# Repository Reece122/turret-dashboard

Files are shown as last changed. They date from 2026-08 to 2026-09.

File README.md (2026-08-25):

<div align="center">

# AutoTurret

**A camera-driven, object-tracking pan/tilt turret** — Jetson-hosted vision, a
closed-loop control law tuned in simulation before it ever touched hardware,
and a live web dashboard to run and tune it from any device on the network.







</div>

<br>

<p align="center">
  <video src="media/drone-3rd-person.mov" controls width="100%">
    Demo video — see <code>media/drone-3rd-person.mov</code>.
  </video>
</p>

---

## Demo

**Drone tracking**

| 3rd person | Dashboard POV |
|---|---|
| <video src="media/drone-3rd-person.mov" controls width="100%"></video> | <video src="media/drone-dashboard-pov.mov" controls width="100%"></video> |

**Ball tracking** — same control law, three motion patterns

| Straight-line | Figure-8 | Pinpoint (acquire/reacquire) |
|---|---|---|
| <video src="media/ball-line.mov" controls width="100%"></video> | <video src="media/ball-figure8.mov" controls width="100%"></video> | <video src="media/ball-pinpoint.mov" controls width="100%"></video> |

## What it is

Two processes talking over HTTP: a **Python/Flask vision server** that owns
the camera, runs YOLO11 detection, and drives two servos over I2C; and a
**Next.js dashboard** that streams the annotated feed, exposes every control
gain as a live slider, and can start/stop/restart the vision server remotely.
Point it at a moving target and it tracks and aims a laser at it in real time.

The interesting part isn't the demo — it's getting from "twitches on a
stationary target, lags behind a fast one" to a single, stable control law
that handles both. That's documented in full in **[DEVLOG.md](DEVLOG.md)**.

## Highlights

- **Velocity feedforward control** — commands the target's own angular rate
  directly instead of waiting for position error to build up, collapsing what
  used to be a fragile two-mode (acquire/track) state machine into one gain
  that's stable at every speed. [Details →](DEVLOG.md#2-the-tracking-control-saga-the-big-one)
- **World-space tracking** — target velocity is estimated in world space
  (image position + camera angle), not image space, so panning to follow the
  target is never mistaken for the target moving.
- **Custom-trained YOLO11 detector** — a from-scratch drone detector
  (mAP@50 0.976) trained and fine-tuned on the Jetson itself, alongside a
  from-scratch OpenCV blob tracker as a no-neural-net fallback mode.
- **Simulated before it was tuned on hardware** — every control-law and gain
  change was validated in a closed-loop 2D simulator first; hardware time was
  spent confirming, not guessing. See `tools/tune.py`.
- **Face-safety clamp** — with an always-on laser payload, aim is hard-clamped
  to at or below the shoulder line whenever the target class is a person.
- **Fully live-tunable** — every PID/Kalman/feedforward gain, camera setting,
  and servo limit is a dashboard slider with immediate effect — no redeploy
  to tune.

## How it works

| Piece | Detail |
|---|---|
| Compute | Jetson Orin Nano 8GB, JetPack 6.2.3 |
| Vision | YOLO11 (pose + custom drone detector) and an OpenCV blob tracker |
| Control | PID + velocity feedforward on a Kalman-filtered world-space estimate |
| Actuation | 2x servos via PCA9685 over I2C |
| Payload | Always-on laser designator |
| Backend | `python_server.py` — Flask + MJPEG stream + vision/control thread, port 8000 |
| Frontend | Next.js 16 / React 19 dashboard, `app/page.tsx`, port 3000 |
| Test rig | `tools/drone_target.html` — animated on-screen target for indoor tuning |

```
┌────────────────────┐        spawns/kills, proxies stream        ┌───────────────────────┐
│  Next.js dashboard  │ ───────────────────────────────────────▶  │  Flask vision server   │
│  (port 3000)        │ ◀───────────────────────────────────────  │  (port 8000)           │
│  live config sliders│        MJPEG feed + telemetry JSON         │  camera → YOLO11/blob  │
└────────────────────┘                                            │  → Kalman → PID+FF     │
                                                                    │  → PCA9685 → servos    │
                                                                    └───────────────────────┘
```

## Hardware & CAD

Full wiring, power domains, and bring-up steps are in **[HARDWARE.md](HARDWARE.md)**.

<p align="center">
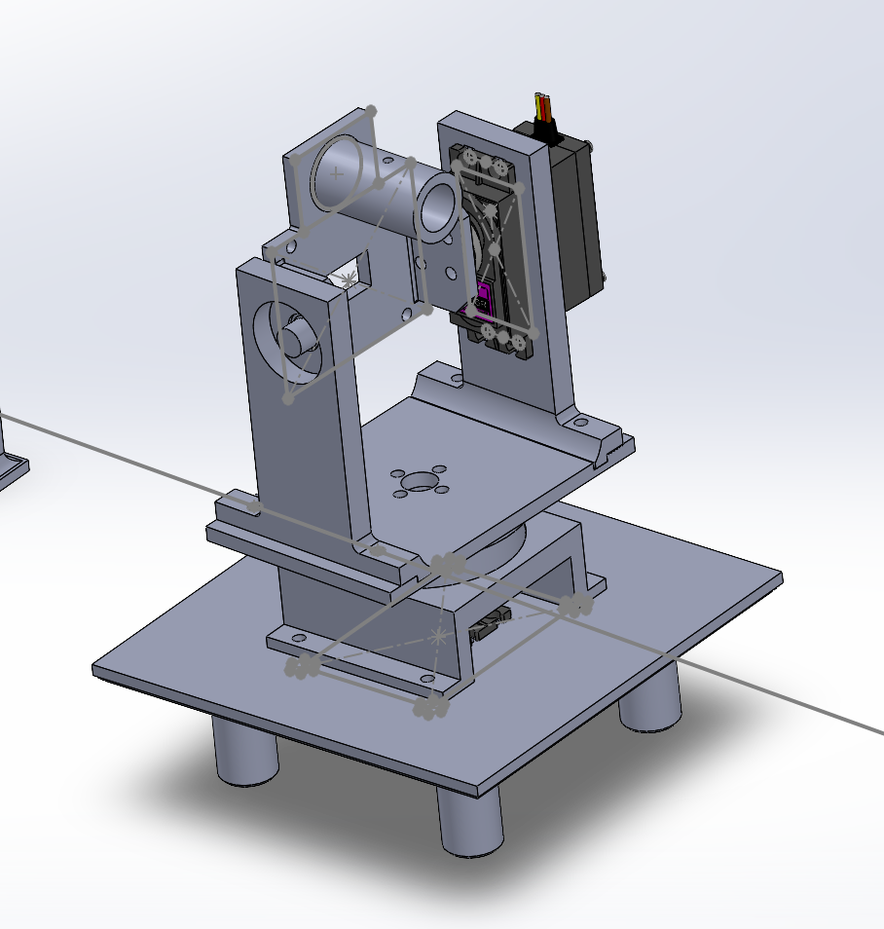
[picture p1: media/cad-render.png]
AutoTurret CAD assembly — pan/tilt mount with servo gearing
  
</p>

CAD source lives in [`/cad`](cad):

| File | Format | Notes |
|---|---|---|
| [`FinalAssembly.SLDASM`](cad/FinalAssembly.SLDASM) | SolidWorks assembly | Full turret assembly, parametric |

## Tech stack

**Frontend:** Next.js 16, React 19, TypeScript
**Backend:** Python, Flask, OpenCV, NumPy
**Vision:** Ultralytics YOLO11 (pose + custom-trained detection), custom Kalman filter
**Hardware:** NVIDIA Jetson Orin Nano, PCA9685 servo driver, 2x hobby servos, USB camera, laser module

## Getting started

```bash
# one-time Jetson setup (Node, Python deps, I2C, systemd service)
sudo bash jetson_setup.sh

# dev — dashboard only (vision server is started from the UI's Start button)
npm run dev

# or reachable from other devices on the LAN
npm run dev:lan
```

The dashboard's **Start** button spawns `python_server.py` (see
`app/api/server/route.ts`); it isn't run manually. With no PCA9685 attached,
servo output degrades to a silent no-op so the vision loop still runs
standalone (e.g. on a laptop against `tools/drone_target.html`).

## Project journal

**[DEVLOG.md](DEVLOG.md)** is the full build log — nine failed approaches to
the tracking-control bug before the actual fix, the 9→15 FPS camera-driver
investigation, the drone-detector training runs, and every hardware bump
along the way. Written to capture *why*, not just *what*, so worth a read if
you want the engineering story rather than just the code.

## Roadmap

Next up, in priority order (latency is the documented bottleneck on
everything below it — see [DEVLOG §12](DEVLOG.md#12-roadmap--planned-improvements)):

1. **Camera fps + quality** — current ~15fps ceiling is USB/MJPG-decode
   throughput; a better sensor fixes both fps and image quality at once.
2. **Better, smoother servos** — hobby-grade MG996R are the current
   mechanical noise floor.
3. **Two-camera distance triangulation** — stereo rig flanking the laser for
   a real distance estimate, not just parallax correction.
4. **Vision model quality** — more/varied training data for the drone
   detector.

## License

No license file yet — all rights reserved by default until one is added.

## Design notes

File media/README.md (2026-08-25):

# Media

Demo footage embedded in the root `README.md`:

| File | Shows |
|---|---|
| `drone-3rd-person.mov` | Tracking a drone target, 3rd-person view (also the hero clip) |
| `drone-dashboard-pov.mov` | Same drone run, from the live dashboard's feed |
| `ball-line.mov` | Ball tracking, straight-line motion |
| `ball-figure8.mov` | Ball tracking, figure-8 motion |
| `ball-pinpoint.mov` | Ball tracking, pinpoint mode (target pops up/vanishes — forces a genuine re-acquire) |
| `cad-render.png` | CAD assembly render, used in the Hardware & CAD section |

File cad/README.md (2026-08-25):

# CAD

| File | Format | Notes |
|---|---|---|
| `FinalAssembly.SLDASM` | SolidWorks assembly | Full turret assembly, parametric. Requires SolidWorks (or eDrawings) to open — no STL/step export included yet. |

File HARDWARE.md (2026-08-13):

# AutoTurret — Hardware wiring

Mental model: **three separate power domains that share one common ground.**
Never cross the rails — the only thing shared across all three is ground.

## Power domains
- **19V barrel-jack supply → Jetson only.**
- **5–6V brick (≥5A) → the PCA9685 V+ screw terminal only** (this powers the servos).
- **3.3V from the Jetson → the PCA9685 VCC** (logic only).

## Jetson 40-pin → PCA9685 (4-wire I2C link)
| Jetson pin | → | PCA9685 |
|---|---|---|
| 3.3V (pin 1) | → | VCC |
| GND (pin 6) | → | GND |
| SDA (pin 3) | → | SDA |
| SCL (pin 5) | → | SCL |

I2C is on **bus 7** on the Orin Nano. Verify the board with:
```bash
sudo i2cdetect -y -r 7      # expect 0x40 to appear
```

## Servo power → PCA9685
- 5–6V brick **+** and **−** → the green **V+ / GND** screw terminal.
- Add a **470–1000µF capacitor** across V+/GND to absorb current spikes.

## PCA9685 → servos
- **Pan servo → channel 0** (3-pin plug: signal / V+ / GND)
- **Tilt servo → channel 1**
- Servos draw power straight from the V+ rail through those headers — no separate wiring.

## Camera
- USB webcam straight into a Jetson USB port. Works with `cv2.VideoCapture(0)`.

## Laser (CHT1230, 3–6V module)
**DECISION: always-on.** No MOSFET, no GPIO, no code — the laser is lit whenever
the rig is powered.
- Wiring: red → 5V (pin 2), black → any GND pin.

<details><summary>Switchable option (not used — kept for reference)</summary>

MOSFET low-side switch:
- red → 5V
- black → MOSFET **drain**
- MOSFET **source** → GND
- Jetson **GPIO (pin 7)** → MOSFET **gate** through **~220Ω**, with a **10kΩ gate-to-source pulldown**.
</details>

## Common ground (do not skip)
Jetson GND, PCA9685 GND, and the 5–6V brick's minus **must all tie together**.
The GND wire in the 4-wire link plus the brick's minus wire already accomplish this.
Without it the servo signals float and jitter.

## Software notes
- Servo driver: `pip3 install adafruit-circuitpython-servokit`; enable I2C.
- **Servo control is implemented** in `python_server.py` (`ServoController`).
  `pan_angle` / `tilt_angle` (0–180°) are written to the PCA9685 each frame.
  With no board attached it degrades to a silent no-op ("sim" mode) so the
  vision loop still runs on a laptop.
- Laser: always-on, hardwired to 5V — no code.
- These live in `turret_config.json` (also settable via `POST /config`), so the
  mechanism can't over-travel and axes can be flipped without rewiring:
  - `servo_enabled` (master on/off), `pan_channel` (0), `tilt_channel` (1)
  - `pan_min` / `pan_max`, `tilt_min` / `tilt_max` (degrees)
  - `pan_invert` / `tilt_invert` (reverse an axis that chases the wrong way)
- First bring-up tip: set `servo_enabled` false, confirm the pan/tilt readouts
  on the dashboard move sanely, then enable. If an axis runs to its limit,
  flip that axis's `invert`.

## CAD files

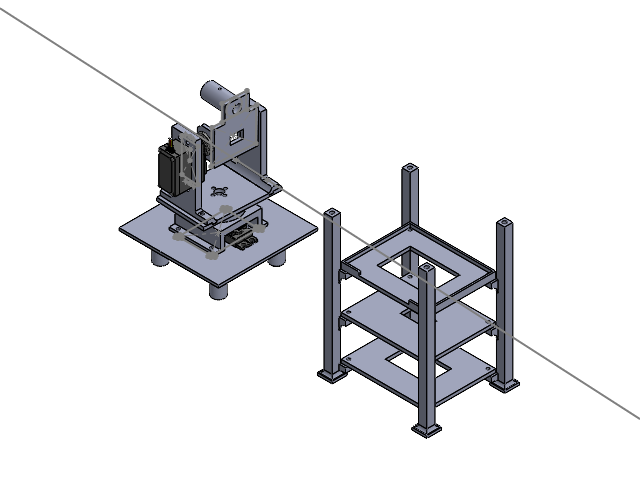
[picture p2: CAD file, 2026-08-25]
cad/FinalAssembly.SLDASM
mg996_arm_round x 2
mg996R_v2 x 2
ThrustBearing

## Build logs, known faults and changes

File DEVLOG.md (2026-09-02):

# AutoTurret — Development Log

A record of the software work on this project: what was built, what was tried,
what broke, and *why* it broke. Written to save re-deriving the same conclusions
(and re-making the same mistakes) later.

---

## 1. System overview

| Piece | Detail |
|---|---|
| Compute | Jetson Orin Nano 8GB, JetPack 6.2.3 |
| Vision | YOLO11 (pose + custom drone detector) and an OpenCV blob tracker |
| Actuation | 2x MG996R servos via PCA9685 over I2C bus 7 |
| Payload | Always-on laser (drives the face-safety logic) |
| Backend | `python_server.py` — Flask + MJPEG stream + single vision thread, port 8000 |
| Frontend | Next.js 16 / React 19 dashboard, `app/page.tsx`, port 3000 |
| Test rig | `tools/drone_target.html` — animated on-screen target |
| Access | Tailscale + LAN; SSH alias `jetson` |

Two processes, and the distinction matters constantly:

- **Dashboard (3000)** — Next.js. Serves the UI, and spawns/kills the vision server
  via `app/api/server/route.ts`.
- **Vision server (8000)** — Python. Owns the camera, inference, PID, servos.

---

## 2. The tracking-control saga (the big one)

This consumed the most time by far. Nine distinct approaches before the right one.

### The original problem

The turret needed aggressive lead + P gain to keep up with a fast target, but
those same settings made it twitch, lurch, or oscillate when the target was slow
or stationary. The intuitive fix — two modes, gentle for acquiring and aggressive
for tracking — turned out to be treating a symptom.

### Why it was actually happening (found at the end, via simulation)

The controller is `pan_angle += kp * error`, which is a **rate** command. For a
target moving at speed `v`, the steady state requires `kp * error = v * dt`, so:

```
permanent lag = v * dt / kp
```

At 15 fps with `kp = 0.09`, a 300 px/s target sits **223 px behind, forever**. The
only way to shrink that with P alone is a big `kp` — but loop delay caps `kp`
before it oscillates, and a big `kp` multiplied by a noisy velocity estimate is
precisely what makes a near-stationary target twitch.

**That bind is the entire reason the two-mode design existed.** The premise
("aggressive gains blow up on slow targets") was correct; the conclusion
("therefore switch gains") was not.

### Attempts, in order

| # | Approach | Why it failed |
|---|---|---|
| 1 | Two modes (acquire/track), switch on distance-to-crosshair | Entering track lurched the aim, which pushed the target off-center, which ejected it back to acquire. Self-reinforcing flapping. |
| 2 | Separate saved presets for acquire and track | Useful UX, but orthogonal to the bug. Didn't address why the switch misfired. |
| 3 | Gate on "consistent velocity direction for N frames" | Instantaneous Kalman velocity is noisy; over a short window even jitter looks directionally consistent. Leaked. |
| 4 | Gate on net travel from where the target first appeared | Better (jitter oscillates in place -> ~0 net travel), but still image-space, so camera panning counted as target travel. |
| 5 | Gate on path straightness (`net displacement / path length`) | Simultaneously too leaky (a single noise jump is perfectly "straight" — one segment always is) and too strict (real curved motion scored low and never locked). |
| 6 | Jump reset — treat any >110 px single-frame jump as a relocation | Correct and kept, but only fixed reflection-snap, not the core issue. |
| 7 | Measure camera rotation *while centered* (parked vs. following) | Clever, calibration-free in principle, but still fragile and indirect. |
| 8 | **Track in world space** (`image position + camera angle`) | **Correct and kept.** Removed ego-motion from the velocity estimate. |
| 9 | Velocity-hysteresis FSM on world speed | Much better, but still a hard switch — so it still toggled at the boundary on real hardware. |
| ✅ | **Velocity feedforward, single mode** | The actual fix. See below. |

### The fix: velocity feedforward

Instead of waiting for position error to accumulate and asking a large gain to
chase it, **command the target's own angular rate directly**:

```python
ffk = ff_gain * dt / px_per_deg
pan_delta = pan_pid.update(error_x) + dvx * ffk
```

The P term then only trims residual error, so it can stay small and stable.
Steady-state lag goes to ~0 at *any* speed, which means one gentle gain covers a
still target and a fast one — **nothing left for a mode switch to do.**

Simulation results (`scratchpad/arch2.py`), constant 300 px/s target:

```
P only (kp .09)                    202 px rms
P + lead                           106 px
P_hi + lead   (the "track" mode)    49 px    jitter at rest: 3.2 px
velocity FEEDFORWARD (kp .09)       20 px    jitter at rest: 1.5 px
```

Feedforward with the *gentle* gain beat the aggressive-gain lead controller by
2.5x on moving targets **and** was half as jittery at rest — better at both ends
at once.

### Corollaries

- **With feedforward, `lead` should be 0.** Sim: lead 0 -> 19.7 px; lead 0.30 ->
  109.6 px. Feedforward already supplies the rate; lead then just parks the aim
  *ahead* of the target. Lead is only meaningful as true projectile flight-time
  lead — pointless for a laser.
- **`kalman_q` was crippled.** It was 82, with `NUMERIC_LIMITS` capping it at 500.
  At q=82 the velocity estimate takes **~4 seconds** to learn a 300 px/s target
  (figure-8 error 333 px). At q=8000 it converges in under a second (156 px).
  Feedforward is only as good as the velocity estimate — and so was every
  "is it moving?" decision, which is a large part of why mode-switching was
  so unreliable. Cap raised to 60000.

### Prior art checked

- **Velocity feedforward** — standard in telescope drives (sidereal tracking
  feedforwards Earth's rate; guiding only trims residual), camera gimbals, and
  every industrial motion controller.
- **Smith Predictor** (1957) — textbook dead-time compensator. Implemented and
  tested; at this rig's actual delay it tied plain feedforward and was *less*
  robust to delay mismatch, so it was not shipped.
- **Track initiation vs. maintenance** — real radar/fire-control does have two
  modes, but they differ in **data association** (which detections belong to the
  track; M-of-N logic, validation gates), **not in controller gains**.
- **IMM (Interacting Multiple Model)** — the principled "might be still, might be
  maneuvering" solution: parallel motion models blended by likelihood, so it
  never hard-toggles.
- **Visual servoing** — the original bug is textbook IBVS ego-motion coupling;
  world-space tracking is effectively PBVS.

### The irreducible limit

Overshoot on an *unpredicted* maneuver is approximately `v * total_latency`
(~100 px at 500 px/s with a ~200 ms loop). No algorithm beats this. Systems like
Phalanx CIWS or high-speed vision rigs win with **kHz sensor rates, not smarter
code**. At ~15 fps, latency is the binding constraint on everything here.

---

## 3. Simulation work

Rather than tuning on hardware (slow, noisy, camera kept dropping), most tuning
moved into closed-loop simulators.

| Script | Purpose | Outcome |
|---|---|---|
| `tools/tune.py` | 2D realistic sim, random search + local refine | Produced the "snappy" preset |
| `speed_sched.py` | Speed-scheduled gains (switch presets by detected speed) | **0% benefit** — system is delay-limited, not gain-limited. Lead compensates delay ~uniformly, and bounces are *also* high-speed, so speed is the wrong scheduling signal. Feature deliberately not built. |
| `tune_screen.py` | Real geometry: 30" 16:9 screen at ~8", 15.8 fps | Found the setup is frame-rate-limited; past ~600 px/s the target clips out of frame regardless of tuning. **Backing the camera off to 14–16" roughly doubles trackable speed** (angular speed = v/d). |
| `fsm_sim.py` | Acquire/track state machine | Validated hysteresis, and exposed a bug in my own sim: `r` was 100x too high, over-smoothing the velocity to ~4°/s when truth was ~30°/s |
| `arch_sim.py` / `arch2.py` / `arch3.py` | Compare control *architectures*, not just gains | Found velocity feedforward. Also caught that v1's numbers were dominated by Kalman velocity convergence time, not the control law |

**Lesson:** twice, the first run of a simulator produced confidently wrong
numbers because of a bug in the *simulator* (bad `r`; transient swamping
steady-state). Always sanity-check sim output against a hand-computed
expectation before acting on it.

---

## 4. Vision & detection

### Blob (ball) tracking

Added an OpenCV path for tracking a bright ball on a dark background — no neural
net: grayscale -> threshold -> `MORPH_OPEN` -> `findContours` ->
`minEnclosingCircle`.

**Problem:** as room light increased, reflections of the light source were picked
up as the ball.

**Fixes:**
- **Roundness gate** — `4*pi*area / perimeter^2`. A ball is round (~0.7–0.9); glare
  is an irregular streak (~0.2–0.4). Falls back to keeping all candidates if the
  gate would reject *everything* (a badly blurred ball), so it can't lose the target.
- **Nearest-to-last-position** selection when multiple round candidates survive —
  the real object moves continuously; glare flares up elsewhere.

### Aim point

- Pose models: head/chest/hand keypoints, `aim_drop` to slide down the torso.
- Detection models (e.g. drone): bounding-box center.
- `aim_offset_y` to strike below the box top (drone body vs. box edge).
- **Face-safety** — with the always-on laser, aim is clamped to at or below the
  shoulder line for people.

### Target loss behavior

Evolved several times:

1. Freeze on loss — guaranteed losing a fast target.
2. Coast along last velocity for `COAST_FRAMES` — better, but caused
   **"shoots off into nothingness."** Two causes: leftover **integral windup**
   kept driving after the target vanished, and coasting a target last seen near
   the frame edge (already on its way out) drove the servo to its travel stop.
3. Clear the integral on loss; don't coast in acquire/pinpoint (next appearance
   is random).
4. **Final:** in track mode, continue the servo's *own last step*, decayed to zero
   over the coast window. It's the step already being applied, scaled down each
   frame — so it cannot wind up or run away. Shows `TRACK (drift)` on the feed.

---

## 5. Camera & hardware

The single most recurring source of "the software is broken" reports — and it was
hardware every time.

### The recurring "no video / can't control servos"

Root cause: **the USB camera physically dropping off the bus.** Not enumerated at
all (`lsusb` showed nothing), so no `/dev/video*`. Software mitigations added:

- `open_camera()` scans indices 0–9 — the device index shifts across re-plugs
  (observed `/dev/video0` -> `/dev/video1` mid-session).
- Camera-fail branch still honors **Center** and keeps servo/FPS telemetry live,
  so a dropped camera doesn't *also* lock out the servos.
- After ~2 s of no frames, release and rescan.

### The 9 FPS discovery

The feed was running at 9 FPS in a dark room. Investigation with `v4l2-ctl` found
**two independent caps**, neither of which the code was addressing:

1. **Format.** The camera (Microdia Vitade AF, `0c45:6366`) does 30 fps in **MJPG**
   at 640x480 but only **10 fps in YUYV** — and OpenCV opens UVC cameras as YUYV
   by default. Forcing `CAP_PROP_FOURCC=MJPG` took it 9.3 -> ~15 fps, halving frame
   latency.
2. **`exposure_dynamic_framerate`** (default on) lets the camera *drop its frame
   rate* to lengthen exposure in a dark room — costing both latency and motion
   blur. Turned off.

Also learned: on this UVC device `cap.set(CAP_PROP_EXPOSURE)` is unreliable;
exposure must go through `v4l2-ctl` (`auto_exposure=1` for manual,
`exposure_time_absolute`, range 1–5000).

Measured, before/after:

```
A default          9.3 fps   fourcc=YUYV
B MJPG + dynFR off 14.9 fps  fourcc=MJPG
C + manual exp     13.7 fps  fourcc=MJPG   <- exposure was NOT the limiter
```

### USB topology

`lsusb -t` showed the camera on **Bus 01 (USB 2.0), behind an intermediate hub**,
sharing that hub with the Bluetooth radio — while **Bus 02 (USB 3.0) sat empty**.
Moving it to a direct port stabilized it. Note: the camera itself is USB 2.0
hardware (480 Mbps), so the port change was about **dedicated power and bus
arbitration**, not bandwidth.

The residual ~15 fps ceiling is MJPG-decode/USB throughput, not exposure — and
opening the camera at MJPG 30 could reset the bus hard enough to drop the SSH
session.

---

## 6. Crashes & the debugging blind spot

### The cv2 float-coordinate crash

**Symptom:** "super laggy... the moment the drone comes on screen it just kinda
pauses."

**Cause:** `cv2.error: Can't parse 'center'. Sequence item with index 1 has a
wrong type` — `aim_offset_y` is stored as a float (NUMERIC_LIMITS coerces via
`clamp(float(value))`), so `ty += aim_offset_y` made `ty` a float, and
`cv2.circle` requires ints.

**Fix:** `tx, ty = int(tx), int(ty)` plus int-casting every draw call.

### The supervisor, and why the logs were empty

Wrapped the vision loop in a supervisor that catches, logs, and restarts after
0.5 s. This turned a permanent freeze into repeating stutters — better
availability, but it also *disguised* the crash.

**Blind spot:** the spawned Python's stdout is buffered, so tracebacks never
reached `journalctl`. Fixed by also appending tracebacks to
`vision_error.log` in the script directory. That file is now the first place to
look.

---

## 7. Drone model training

Goal: a custom drone detector to replace COCO classes.

**Bump 1 — Roboflow SDK doesn't download weights.** `v.download()` fetches the
**dataset**, not trained weights (`cp: cannot stat 'drone_dl/weights.pt'`).
Weights require the UI "Download Weights" button, or training locally.

**Bump 2 — OOM on the Jetson.** Local training died with `[1]+ Killed`. The Orin
Nano's 8 GB is **unified** (shared CPU/GPU), and 6 dataloader workers exhausted
it. Fixed by stopping the turret service, adding 8 GB of swap, and retraining
with `batch=4 workers=2`. Completed: 50 epochs, 5.26 h, **mAP@50 0.976**.

**Bump 3 — weights not where expected.** Ultralytics nested them one level
deeper than assumed: `runs/detect/drone_train/run1/weights/best.pt`.

**Bump 4 — bad UI label.** The dashboard's `modelLabel` abbreviated filenames, so
`drone.pt` rendered as "D DET". Fixed to show custom model filenames verbatim, and
the backend now reports the loaded model's actual class names so the target-class
dropdown reads `0 — drone`.

---

## 8. Deployment & infrastructure bumps

These cost real time and were mostly *not* code bugs.

| Bump | Detail |
|---|---|
| **`systemctl restart` does NOT reload vision code** | The service manages the Next dashboard. The Python vision server is spawned separately — it only reloads on **Stop -> Start** in the UI. Multiple "it's still happening" reports were simply the old Python still running. |
| **The stale-server trap** | Confirmed by querying `/config` for keys that only exist in new code. At one point the running server was **two versions behind** every fix being tested. Always verify what's actually loaded before diagnosing. |
| **dev vs. prod Next.js** | `next dev` hot-reloads `page.tsx`; `next start` serves a **pre-built** bundle and ignores file changes until `npm run build`. A restart silently flipped modes, so UI edits appeared to do nothing. |
| **Browser cache** | Even after rebuild, a normal refresh reused the cached bundle. `Ctrl+Shift+R` required. |
| **`sudo` over non-interactive SSH** | `sudo systemctl restart` fails with "a password is required" — can't be automated from here. Worked around by relaunching the dashboard outside systemd with `setsid`. |
| **SIGTERM to a systemd main PID** | Reads as a *clean stop*, so `Restart=on-failure` does **not** respawn it. Left the dashboard down until manually restarted. |
| **Wrong host** | `localhost:3000` hit the dev laptop, not the Jetson. |
| **Repurposed config keys kept stale values** | `lock_min_travel` changed meaning from "50 px" to "70 px/s" but the saved `turret_config.json` still held `10` — semantically wrong under the new code, so everything tripped instantly. **Renaming a key's units silently poisons saved configs.** |
| **Encoding corruption** | Patching files via a bash heredoc + `open(p,'w')` on Windows wrote **cp1252**, mangling em-dashes/`x` into bytes that are invalid UTF-8. Broke Turbopack (`failed to convert rope into string`) and Python (`Non-UTF-8 code starting with '\x97'`). **Always pass `encoding='utf-8'` explicitly.** Repaired byte-exactly rather than by re-typing. |

---

## 9. Dashboard / UX work

- Target class: slider -> **dropdown** populated from the loaded model's real class
  names (falls back to COCO).
- Model card -> **Tracking** card: YOLO vs. Ball(blob) toggle, with blob controls
  (brightness threshold, min size, roundness gate) shown contextually.
- Pose-only controls hidden for detection models.
- **Center** button moved into the header (was buried and required scrolling).
- Live **mode badge** painted onto the video feed *and* in the sidebar.
- **Two-namespace presets** — independent `acquire` and `track` libraries that can
  be mixed and matched, with legacy flat presets auto-migrated into `track`.
  (Largely vestigial now that the controller is single-mode, but harmless.)

## 10. Test target page (`tools/drone_target.html`)

Self-contained animated target, since a real drone indoors isn't practical.

- Real drone sprite from the model's own training data (base64-embedded).
- **Bug:** changing the speed slider teleported the target — zoom/figure-8 used
  `this.t * cfg.speed`, so changing `speed` retroactively rewrote the phase.
  Fixed with a `this.a` phase accumulator (`this.a += dt * cfg.speed`).
- Modes: wander, sweep H/V, zoom, figure-8, **pinpoint** (random pop-ups with a
  deliberate blank between them, forcing a genuine re-acquire).
- **Ball** target on black for blob mode, with color picker.
- **Spawn radius** slider — pop-ups were landing outside the camera's field of
  view; this constrains them to a disk around screen center.
- Idle "bob" was briefly removed to stop it reading as motion, then **restored** —
  the correct fix was on the turret side, not by making the test easier.

---

## 11. Current state

Single control law, no mode switching. Live config:

```
ff_gain 0.9   kalman_q 8000   kalman_r 1
kp 0.15       ki 0            kd 0.005
lead 0        deadband 15     predictor ema
px_per_deg 10.7
```

Running at ~14–15 fps, no crashes. Q ceiling raised to 60000. The dashboard
exposes a **Feedforward** slider (set to 0 to A/B against the old behavior).

### Diagnostics: latency + slew rate

Added to get real numbers instead of estimates:

- **`loop_latency_ms`** in `/telemetry` — smoothed capture-read-to-servo-write
  processing time per frame. Deliberately *not* claimed as total glass-to-servo
  latency: camera driver/USB buffering happens below this process and isn't
  visible to it.
- **`POST /bench/slew`** (`{"axis": "pan"|"tilt", "duration": 2.5}`), polled
  via `GET /bench/slew` — steps the axis to its far travel limit and measures
  the camera's *actual* angular velocity from frame-to-frame background shift
  (`cv2.phaseCorrelate`, converted through `px_per_deg`), not just the
  commanded angle. There's no position encoder on this rig, so watching the
  scene move is the only way to see real servo speed. Needs the camera aimed
  at any normal textured, static scene — a blank wall gives nothing to
  correlate against. Runs inside the vision thread (gated behind
  `slew_bench["active"]`) so it can't race the camera or fight tracking's own
  servo writes; any internal error aborts just the benchmark.
- Not yet run against real hardware — thresholds (benchmark duration, the
  10%-of-peak cutoff for the "in motion" average) are first-pass defaults and
  may need adjusting once real samples come back.

### `ff_gain` = 1.0 is an instability boundary, not just "exact"

`ff_gain 1.0` was originally described as exact cancellation of the target's
motion — true against a *real* moving target, but there's a second case: a
false target that's actually fixed in the image (e.g. a lens reflection).
There, the loop gain **is** `ff_gain` itself — each frame's commanded pan
delta equals `ff_gain` times the previous one — so at 1.0 it self-sustains and
above 1.0 it diverges. Running at **0.9** damps that oscillation while still
handing the P term only ~10% of the motion to trim. Don't run at 1.0+.

### Key invariants — don't regress these

1. **Feed the Kalman world position, never raw image position.**
   `world_x = tx + (±pan_angle) * px_per_deg`. Image-space velocity cannot
   distinguish "target moved" from "camera moved."
2. **Keep velocity feedforward.** It's what makes a single gain work across all
   speeds. Without it, the two-mode bind returns.
3. **`lead` stays 0** unless firing an actual projectile.
4. **`kalman_q` must stay large** (thousands). Feedforward is only as good as the
   velocity estimate.
5. **`ff_gain` stays below 1.0** (currently 0.9) — 1.0+ self-sustains against a
   static false target. See above.
6. **Restart the vision server (Stop -> Start) to load Python changes.** A page
   refresh or `systemctl restart` is not enough.

---

## 12. Roadmap — planned improvements

Everything here traces back to the same root finding from §2: at ~15 fps,
**latency is the binding constraint**, not control-loop tuning. The control
law is done; the next real gains are hardware and pipeline, in priority order.

1. **FPS.** The current ~14–15 fps ceiling is MJPG-decode/USB throughput (§5),
   and it caps *everything downstream* — tracking, servo smoothness, all of
   it. Candidates: a camera with real USB3/higher native throughput, cutting
   pipeline stages, or moving inference off the frame-capture thread.
2. **Camera quality.** Better sensor/lens = less motion blur and a cleaner
   signal into the detector, which is now the second-order error source now
   that ego-motion and steady-state lag are solved. Related, already-known
   lever: moving the camera from ~8" to 14–16" roughly doubles trackable
   angular speed for free (`w = v/d`, found via `tune_screen.py`, §3).
3. **Vision model quality.** The custom drone detector hit mAP@50 0.976 (§7)
   but was trained on a small, single-session dataset — more/varied training
   data, and revisiting the blob tracker's glare-rejection heuristics (§4),
   are the next targets.
4. **Two-camera design for target distance (triangulation).** Previously
   scoped as "laser parallax" — flanking the laser with two cameras. Three
   options discussed: **(a)** average the two centroids to approximate a
   virtual camera at the laser (simplest, corrects parallax only), **(b)**
   true stereo triangulation for a real distance estimate (enables
   distance-aware aim correction, projectile drop compensation, etc.),
   **(c)** single-camera parallax correction using a fixed offset (cheapest,
   least capable). Distance triangulation (b) is the growth path — it's a
   superset of what (a) fixes. Bore-sight offset and servo backlash are
   separate error sources from parallax and would still need their own
   calibration.
5. **Better, smoother servos.** MG996R are hobby-grade — coarse steps and
   noticeable jitter at small deltas. Higher-resolution or digital/serial
   servos (or closed-loop servos with their own position feedback) would cut
   the mechanical noise floor the control loop is currently fighting under.

### Housekeeping (do before/while publishing)

- **Rotate the Roboflow API key** — it was pasted into a chat transcript
  (never committed) and should be regenerated in Roboflow Settings -> API
  Keys before this repo goes public.
- **Secrets scan (2026-08-19): clean.** Grepped all tracked files for
  key/token/secret/password/wifi patterns — no hits. `.claude/settings.local.json`
  (holds a WiFi credential) is gitignored and confirmed untracked. Re-run this
  scan if more config files are added before publishing.
- **USB stability** — improved by the direct-port move (§5); worth continuing
  to watch under real-world use.

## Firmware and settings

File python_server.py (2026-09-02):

from flask import Flask, Response, jsonify, request
from flask_cors import CORS
from ultralytics import YOLO
import numpy as np
import cv2
import time
import json
import os
import glob
import threading
import subprocess
from collections import deque

# Tuning is saved here so it survives a server restart. Anchored to this
# script's own folder so it's found no matter where the server is launched from.
SCRIPT_DIR = os.path.dirname(os.path.abspath(__file__))
CONFIG_FILE = os.path.join(SCRIPT_DIR, "turret_config.json")
PRESETS_FILE = os.path.join(SCRIPT_DIR, "turret_presets.json")

app = Flask(__name__)
CORS(app)   # lets the dashboard (running on a different port) read our data

# Pose models the dashboard is allowed to switch between. Bigger = steadier
# keypoints but slower. On the Jetson you'd point these at .engine files.
ALLOWED_MODELS = ["yolo11n-pose.pt", "yolo11s-pose.pt", "yolo11m-pose.pt", "yolo11n.pt"]


def available_models():
    """Base pose/detection models plus any *.pt / *.engine dropped into the
    script folder — so a downloaded drone model shows up in the dashboard
    automatically. Only local files are ever loadable (no arbitrary paths)."""
    found = [os.path.basename(p)
             for p in glob.glob(os.path.join(SCRIPT_DIR, "*.pt"))
             + glob.glob(os.path.join(SCRIPT_DIR, "*.engine"))]
    return list(dict.fromkeys(ALLOWED_MODELS + sorted(found)))

# Which body part the turret aims at. Values map to COCO pose keypoint indices.
AIM_MODES = {
    "head": [0, 1, 2],   # nose, left eye, right eye
    "chest": [5, 6],     # left shoulder, right shoulder
    "hand": [9, 10],     # left wrist, right wrist
}

PREDICTORS = ["none", "ema", "kalman"]

# Everything the dashboard can tune live. POST /config to change it.
config = {
    "model": "yolo11n-pose.pt",
    "aim": "chest",          # head | chest | hand (pose models only)
    "target_class": 0,       # class index to track (pose:0=person; drone model:0)
    "auto_q": False,         # scale Kalman Q with target size (for depth changes)
    "aim_drop": 0.2,         # chest: slide aim down toward hips (0=shoulders,1=hips)
    "aim_offset_y": 0,       # px to aim below (+) / above (-) the target point
    "face_safe": False,      # never let the aim/laser rise above the shoulders
    "track_mode": "yolo",    # "yolo" (model) | "blob" (bright ball on dark bg)
    "blob_thresh": 60,       # blob mode: brightness (0-255) above which = target
    "blob_min_area": 150,    # blob mode: ignore blobs smaller than this (px area)
    "blob_circularity": 0.45,  # blob mode: min roundness (0-1). A ball is round; a
                             # light reflection is usually an irregular streak, so
                             # this rejects glare even when there's only one blob.
    "cam_manual_exposure": False,  # force a fixed short exposure (see cam_exposure).
                             # Turn ON in a dark room: kills the auto-exposure that
                             # drops FPS + blurs motion. Off = normal auto-exposure.
    "cam_exposure": 150,     # manual exposure (device units; lower = faster+sharper
                             # but darker). Slide down until FPS jumps and blur goes,
                             # adding room light to keep the ball bright.
    "predictor": "ema",      # none | ema | kalman
    "lead": 0.0,             # seconds to aim AHEAD of the target. With
                             # feedforward this is a deliberate projectile-lead
                             # offset, not lag compensation - 0 points AT it.
    "deadband": 15,          # px of slop before the PID reacts
    "kp": 0.15, "ki": 0.0, "kd": 0.005,     # PID gains. With feedforward
                             # carrying the motion, kp only trims residual error -
                             # it no longer has to be aggressive, and ki is not
                             # needed to kill steady-state lag (FF already does).
    "ff_gain": 0.9,          # velocity feedforward: fraction of the target's own
                             # angular rate to command. 1.0 cancels the motion
                             # exactly BUT is the stability boundary: against a
                             # false target that is fixed in the image, the loop
                             # gain IS ff_gain, so 1.0 self-sustains and >1.0
                             # diverges. 0.9 decays those oscillations while
                             # leaving only ~10% of the motion for the P term to
                             # trim. Do not run at 1.0 or above. 0 = off.
    "kalman_q": 8000.0,      # Kalman process noise (accel variance). Must be LARGE
                             # here: q is what lets the velocity estimate converge
                             # quickly, and feedforward is only as good as that
                             # estimate. (Sim: q=82 took ~4 s to learn a 300 px/s
                             # velocity and tracked a figure-8 at 333 px error;
                             # q=8000 converges in <1 s and halves the error.)
    "kalman_r": 1.0,         # Kalman measurement noise (blob centroid is precise)

    "move_threshold": 70,    # px/s of world speed above which the UI badge reads
                             # MOVING. Display only - the control law is the same
                             # at every speed now (feedforward), so nothing switches.
    "px_per_deg": 10.7,      # camera pixels per degree of servo rotation. Used to
                             # subtract the camera's OWN motion when judging whether
                             # the target is really moving — so panning to center a
                             # still ball doesn't read as the ball moving. Roughly
                             # frame_width / horizontal_FOV. Raise/lower it if a
                             # still target still trips into track while centering.

    # Servo output (PCA9685 over I2C). Channels are wired once at build time;
    # the min/max travel limits keep the mechanism from over-rotating; invert
    # flips an axis's direction if a servo is mounted the "wrong" way.
    "servo_enabled": True,   # master switch — off to tune the loop without moving
    "pan_channel": 0,        # PCA9685 channel for the pan servo
    "tilt_channel": 1,       # PCA9685 channel for the tilt servo
    "pan_min": 0.0, "pan_max": 180.0,     # allowed pan travel (degrees)
    "tilt_min": 0.0, "tilt_max": 180.0,   # allowed tilt travel (degrees)
    "pan_invert": False,     # reverse pan if it chases the wrong way
    "tilt_invert": False,    # reverse tilt if it chases the wrong way
    "pan_center": 90.0,      # "home" pan angle (Center button + startup)
    "tilt_center": 110.0,    # "home" tilt angle — biased up to offset droop
}

# Allowed range for each numeric setting, used to clamp incoming values.
NUMERIC_LIMITS = {
    "lead": (0.0, 1.0),
    "aim_drop": (0.0, 1.0),
    "aim_offset_y": (-300, 300),
    "blob_thresh": (0, 255),
    "blob_min_area": (10, 100000),
    "blob_circularity": (0.0, 1.0),
    "cam_exposure": (1, 2000),
    "deadband": (0, 100),
    "kp": (0.0, 0.3),
    "ki": (0.0, 0.05),
    "kd": (0.0, 0.1),
    "kalman_q": (1.0, 2000000.0),
    "kalman_r": (0.1, 50.0),
    "ff_gain": (0.0, 2.0),
    "move_threshold": (0, 2000),
    "px_per_deg": (0.0, 100.0),
    "pan_min": (0.0, 180.0), "pan_max": (0.0, 180.0),
    "tilt_min": (0.0, 180.0), "tilt_max": (0.0, 180.0),
    "pan_center": (0.0, 180.0), "tilt_center": (0.0, 180.0),
}

# Settings that are plain on/off flags and 0-15 PCA9685 channel numbers.
BOOL_SETTINGS = ("servo_enabled", "pan_invert", "tilt_invert", "face_safe", "auto_q",
                 "cam_manual_exposure")
CHANNEL_SETTINGS = ("pan_channel", "tilt_channel")

# One saved parameter set = everything that shapes the control loop.
PRESET_KEYS = ("kp", "ki", "kd", "lead", "deadband", "kalman_q", "kalman_r",
               "ff_gain", "predictor", "px_per_deg", "move_threshold")

# When the target blinks out, keep driving the aim along its last velocity for
# this many frames before giving up — long enough to ride through a brief blur or
# a clip off the frame edge, short enough not to run away on a real disappearance.
COAST_FRAMES = 6

# If the gap since we last saw this target exceeds this, treat the next sighting
# as a NEW target rather than computing velocity across the gap. After a camera
# dropout or a long occlusion prev_target_t is stale, so (pos - prev_pos)/dt and
# the Kalman step both produce a garbage velocity spike -- which feedforward then
# faithfully executes, walking the turret off-target. Observed: a camera hiccup
# yielded a phantom 1466 px/s and the aim drifted right off the screen.
MAX_TRACK_GAP = 0.5   # seconds

# Feedforward safety. Against a false target that is fixed in the IMAGE (a lens
# artifact, an auto-exposure hotspot, a motion-blurred highlight) the loop gain is
# exactly ff_gain: world_vel = px_per_deg * pan_rate, so the commanded pan_delta
# equals ff_gain * the previous pan_delta. At ff_gain 1.0 that self-sustains and
# above it diverges -- observed as the turret swinging its full travel with
# phantom speeds of 3000+ px/s. A real, world-fixed target cannot do this. So:
# ignore implausible speeds outright, and cap how far feedforward can move the
# servo in one frame, which bounds the runaway without weakening real tracking.
MAX_WORLD_SPEED = 4000.0   # px/s above which the estimate is treated as bogus
                           # (a real fast target hit 2700 px/s, so this only
                           #  catches genuinely impossible estimates)
MAX_FF_DEG = 4.0           # max degrees of feedforward per frame (~60 deg/s)

# A detection that jumps more than this many px in a single frame isn't real
# target motion (nothing physical moves that fast frame-to-frame here) — it's the
# blob snapping to a reflection or residual. The motion gate treats it as a
# relocation (fresh start point) instead of counting it as travel, so a jump can't
# false-trigger a track lock.
MAX_JUMP = 110

# Cap how far (px) the PREDICTED aim point may lead the measured target. A noisy
# Kalman velocity (high Q) times a big lead can momentarily fling the prediction
# across the frame, and the aim lurches at it for a frame before it settles.
# Bounding the lead offset keeps prediction useful without that teleport/lurch.
MAX_LEAD_PX = 150



# The live numbers the web page reads every frame.
telemetry = {
    "fps": 0.0, "target_id": None,
    "offset_x": 0, "offset_y": 0,
    "pan": 90.0, "tilt": 90.0,
    "p": 0.0, "i": 0.0, "d": 0.0,
    "speed": 0,
    "lead_frac": 0.0,   # fraction of full lead currently applied (0=off, 1=full)
    "mode": "holding",  # "moving" | "holding" - display only; one control law
    "servo": "off",   # "on" (driving hardware) | "off" (disabled) | "sim" (no board)
    "loop_latency_ms": 0.0,  # smoothed capture-read -> servo-write processing
                              # time. NOT total glass-to-servo latency - it
                              # excludes camera driver/USB buffering, which
                              # this process can't see.
}

# One-shot commands from the dashboard the vision loop picks up each frame.
control = {"recenter": False}

# Diagnostic slew-rate benchmark: steps one axis to its far travel limit and
# measures the camera's ACTUAL angular velocity from frame-to-frame
# background shift (phase correlation against px_per_deg), not just the
# commanded angle. There's no position encoder on this rig, so watching the
# scene move IS the only way to see real (not commanded) servo speed - it
# needs the camera looking at any normal textured, static scene (a shelf, a
# cluttered desk; a blank wall won't have anything to correlate against).
# Runs inside the vision thread itself (see _slew_bench_step) so it can't
# race the camera or fight the tracking loop's own servo writes. Only active
# when explicitly started via POST /bench/slew; any internal error aborts it
# without touching tracking.
slew_bench = {"active": False}

# The single vision thread publishes its latest annotated JPEG here; every
# /video viewer just streams this shared buffer. One camera, one capture — so
# extra tabs, refreshes, or reconnects can never fight over the device.
frame_lock = threading.Lock()
latest_jpeg = None

# Class names of the currently-loaded model (e.g. {0: "drone"} or the COCO
# 0-79 map). Published so the dashboard's target-class dropdown labels match
# whatever model is actually active, instead of always assuming COCO.
current_names = {}


def clamp(value, low, high):
    return max(low, min(high, value))


def apply_updates(data):
    """Validate and merge a dict of settings into config (unknown keys ignored,
    numbers clamped). Returns True if anything actually changed."""
    changed = False
    for key, value in data.items():
        if key == "model" and value in available_models():
            config["model"] = value
            changed = True
        elif key == "target_class":
            try:
                config["target_class"] = int(clamp(int(value), 0, 99))
                changed = True
            except (TypeError, ValueError):
                pass
        elif key == "aim" and value in AIM_MODES:
            config["aim"] = value
            changed = True
        elif key == "predictor" and value in PREDICTORS:
            config["predictor"] = value
            changed = True
        elif key == "track_mode" and value in ("yolo", "blob"):
            config["track_mode"] = value
            changed = True
        elif key in BOOL_SETTINGS:
            config[key] = bool(value)
            changed = True
        elif key in CHANNEL_SETTINGS:
            try:
                config[key] = int(clamp(int(value), 0, 15))
                changed = True
            except (TypeError, ValueError):
                pass
        elif key in NUMERIC_LIMITS:
            try:
                low, high = NUMERIC_LIMITS[key]
                config[key] = clamp(float(value), low, high)
                changed = True
            except (TypeError, ValueError):
                pass
    return changed


def save_config():
    """Write current settings to disk so they persist across restarts."""
    try:
        with open(CONFIG_FILE, "w") as f:
            json.dump(config, f, indent=2)
    except OSError as exc:
        print("Could not save config:", exc)


def load_config():
    """Restore saved settings on startup, if the file exists and is valid."""
    if not os.path.exists(CONFIG_FILE):
        return
    try:
        with open(CONFIG_FILE) as f:
            apply_updates(json.load(f))
        print("Loaded saved config from", CONFIG_FILE)
    except (OSError, ValueError) as exc:
        print("Could not load config, using defaults:", exc)


def load_presets():
    """Named parameter sets, {name: {settings...}}. Two older layouts are migrated
    on read: the acquire/track split (from the retired two-mode controller) is
    flattened, track winning on a name clash, and pre-namespace files are trimmed
    to just the keys a preset owns."""
    raw = {}
    if os.path.exists(PRESETS_FILE):
        try:
            with open(PRESETS_FILE) as f:
                raw = json.load(f)
        except (OSError, ValueError):
            raw = {}
    if not isinstance(raw, dict):
        return {}
    if "acquire" in raw or "track" in raw:          # retired two-namespace layout
        merged = {}
        for kind in ("acquire", "track"):
            for n, c in (raw.get(kind) or {}).items():
                if isinstance(c, dict):
                    merged.setdefault(n, {}).update(c)
        raw = merged
    return {n: {k: c[k] for k in PRESET_KEYS if k in c}
            for n, c in raw.items() if isinstance(c, dict)}


def save_presets(presets):
    try:
        with open(PRESETS_FILE, "w") as f:
            json.dump(presets, f, indent=2)
    except OSError as exc:
        print("Could not save presets:", exc)


def aim_point(kpts, confs, mode, drop=0.0):
    """Pick the pixel to aim at for the chosen mode.

    head/chest average the visible keypoints; hand locks onto a SINGLE wrist
    (the more confident one) so we never aim at the empty space between two
    far-apart hands. Returns (x, y) or None when none of that part's keypoints
    are visible (YOLO reports missing keypoints as (0, 0)).
    """
    indices = AIM_MODES.get(mode, AIM_MODES["chest"])
    visible = [i for i in indices if kpts[i][0] > 0 and kpts[i][1] > 0]
    if not visible:
        return None
    if mode == "hand":
        best = max(visible, key=lambda i: confs[i] if confs is not None else 0.0)
        return int(kpts[best][0]), int(kpts[best][1])
    ax = sum(kpts[i][0] for i in visible) / len(visible)
    ay = sum(kpts[i][1] for i in visible) / len(visible)
    # For chest, slide the aim down toward the hips by `drop` (0..1).
    if mode == "chest" and drop > 0:
        hips = [i for i in (11, 12) if kpts[i][0] > 0 and kpts[i][1] > 0]
        if hips:
            hx = sum(kpts[i][0] for i in hips) / len(hips)
            hy = sum(kpts[i][1] for i in hips) / len(hips)
            ax += drop * (hx - ax)
            ay += drop * (hy - ay)
        elif len(visible) == 2:
            # Hips out of frame — estimate torso length from shoulder width.
            sw = abs(kpts[visible[0]][0] - kpts[visible[1]][0])
            ay += drop * 1.5 * sw
    return int(ax), int(ay)


class PID:
    def __init__(self, kp, ki, kd):
        self.kp, self.ki, self.kd = kp, ki, kd
        self.integral = 0.0
        self.prev_error = 0.0
        self.prev_time = time.perf_counter()
        self.p = self.i = self.d = 0.0

    def update(self, error):
        now = time.perf_counter()
        dt = now - self.prev_time
        if dt <= 0:
            dt = 1e-3
        self.p = self.kp * error
        self.integral = clamp(self.integral + error * dt, -1000, 1000)
        self.i = self.ki * self.integral
        self.d = self.kd * (error - self.prev_error) / dt
        self.prev_error = error
        self.prev_time = now
        return self.p + self.i + self.d


class Kalman2D:
    """Constant-velocity Kalman filter for a 2D point in pixels.

    State is [x, y, vx, vy]. It smooths noisy detections and lets us predict
    the position some time ahead, while coasting on momentum through frames
    where the target is briefly missed.
    """

    def __init__(self):
        self.reset()

    def reset(self):
        self.x = None    # state vector, lazily created on first measurement
        self.P = None    # covariance

    def step(self, mx, my, dt, q, r):
        # (Re)initialise on first sight or if time went backwards.
        if self.x is None or dt <= 0:
            self.x = np.array([mx, my, 0.0, 0.0], dtype=float)
            self.P = np.eye(4) * 500.0
            return

        F = np.array([[1, 0, dt, 0],
                      [0, 1, 0, dt],
                      [0, 0, 1, 0],
                      [0, 0, 0, 1]], dtype=float)
        dt2, dt3, dt4 = dt * dt, dt ** 3, dt ** 4
        Q = q * np.array([[dt4 / 4, 0, dt3 / 2, 0],
                          [0, dt4 / 4, 0, dt3 / 2],
                          [dt3 / 2, 0, dt2, 0],
                          [0, dt3 / 2, 0, dt2]], dtype=float)
        H = np.array([[1, 0, 0, 0],
                      [0, 1, 0, 0]], dtype=float)
        R = np.eye(2) * r

        # Predict.
        self.x = F @ self.x
        self.P = F @ self.P @ F.T + Q
        # Correct with the new measurement.
        z = np.array([mx, my], dtype=float)
        y = z - H @ self.x
        S = H @ self.P @ H.T + R
        K = self.P @ H.T @ np.linalg.inv(S)
        self.x = self.x + K @ y
        self.P = (np.eye(4) - K @ H) @ self.P

    def predict(self, t):
        """Where the target should be t seconds from now."""
        return float(self.x[0] + self.x[2] * t), float(self.x[1] + self.x[3] * t)

    def velocity(self):
        return float(self.x[2]), float(self.x[3])


class ServoController:
    """Drives the pan/tilt servos through a PCA9685 over I2C.

    If the adafruit-servokit library or the board itself isn't present (e.g.
    running the vision loop on a laptop with no hardware attached), it degrades
    to a silent no-op so the rest of the server keeps working. Check `.ok` to
    tell live hardware apart from simulation.
    """

    def __init__(self):
        self.kit = None
        self.ok = False
        self._warned = False
        try:
            from adafruit_servokit import ServoKit
            self.kit = ServoKit(channels=16)
            self.ok = True
            print("PCA9685 servo driver ready.")
        except Exception as exc:
            # ImportError on a dev laptop, or an I2C/board error on the Jetson.
            print("Servo driver unavailable — running in simulation "
                  "(no hardware output):", exc)

    def write(self, channel, angle):
        """Send an angle (0-180) to one channel. Safe no-op without hardware."""
        if not self.ok:
            return
        try:
            self.kit.servo[int(channel)].angle = float(clamp(angle, 0, 180))
        except Exception as exc:
            # A transient wiring/I2C hiccup shouldn't crash the vision loop.
            if not self._warned:
                print("Servo write failed (further errors suppressed):", exc)
                self._warned = True
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

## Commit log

2026-08-13 AutoTurret: object-tracking turret — Next.js dashboard + Flask YOLO11 vision/servo server
2026-08-24 Portfolio-ready docs + velocity feedforward control law
    - README: full rewrite from create-next-app boilerplate into a proper
    project page (demo video slot, highlights, architecture, hardware/CAD
    links, roadmap)
    - DEVLOG: complete build log, including the tracking-control saga and the
    fix (velocity feedforward), simulation work, vision/hardware debugging
    - python_server.py / app: single-mode PID + velocity feedforward control
    law replaces the old two-mode acquire/track state machine; live
    Feedforward slider added to the dashboard
    - tools/tune.py: simulator updated to match the new control law
    - tools/drone_target.html: animated on-screen test target rig (self-
    contained, sprite e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
    [python_server.py]
2026-08-25 Add demo videos and turret CAD assembly
    - media/: 5 clips (drone 3rd-person + dashboard POV, ball line/figure-8/
    pinpoint) wired into the README as a Demo gallery
    - cad/: SolidWorks assembly of the full turret
    - README: replaced the single hero-video placeholder with a two-subject
    demo gallery, and pointed the hardware/CAD table at the real file
    [FinalAssembly.SLDASM]
2026-08-25 Strip audio from demo clips
    Stream-copied (no re-encode) to drop the audio track from all 5 videos.
2026-08-25 Add CAD render to README
    Embeds a screenshot of the assembled turret CAD in the Hardware & CAD
    section.
2026-09-02 Add latency and slew-rate diagnostics
    - telemetry.loop_latency_ms: smoothed capture-read-to-servo-write
    processing time (explicitly not total glass-to-servo latency - camera
    driver/USB buffering is invisible to this process)
    - POST/GET /bench/slew: measures real (not commanded) servo angular
    velocity via frame-to-frame optical background shift during a full-
    range step, since this rig has no position encoder
    Untested on real hardware - gated behind explicit triggers and wrapped
    to fail safe without affecting tracking.
    [python_server.py]
2026-09-03 Compact the dashboard sidebar into a 3-column layout
    The tuning sidebar was a single long column of 7 cards, forcing a tall
    page scroll. Switched it to a CSS multi-column layout (masonry-style
    packing, more even than a plain grid given how unevenly tall the cards
    are) plus tighter card/slider spacing, so the whole dashboard now fits
    one normal viewport with no scrolling.
